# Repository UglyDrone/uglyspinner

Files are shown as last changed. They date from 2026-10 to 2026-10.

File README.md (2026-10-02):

# ESP32 Automated Motor & Propeller Test Stand Firmware

Firmware for the **LILYGO TTGO T7 V1.3 Mini32 (ESP32)** automating static motor and propeller thrust testing.

The system commands an **AM32** electronic speed controller (e.g. **SEQURE 130A ESC**) using high-speed digital **DShot600/300**, decodes real-time **KISS/AM32 ESC telemetry**, measures mechanical thrust/load from an **HX711 UART load cell module**, orchestrates multi-step ramp tests, visualizes real-time performance on a self-contained web dashboard, and exports datasets in standard JSON format.

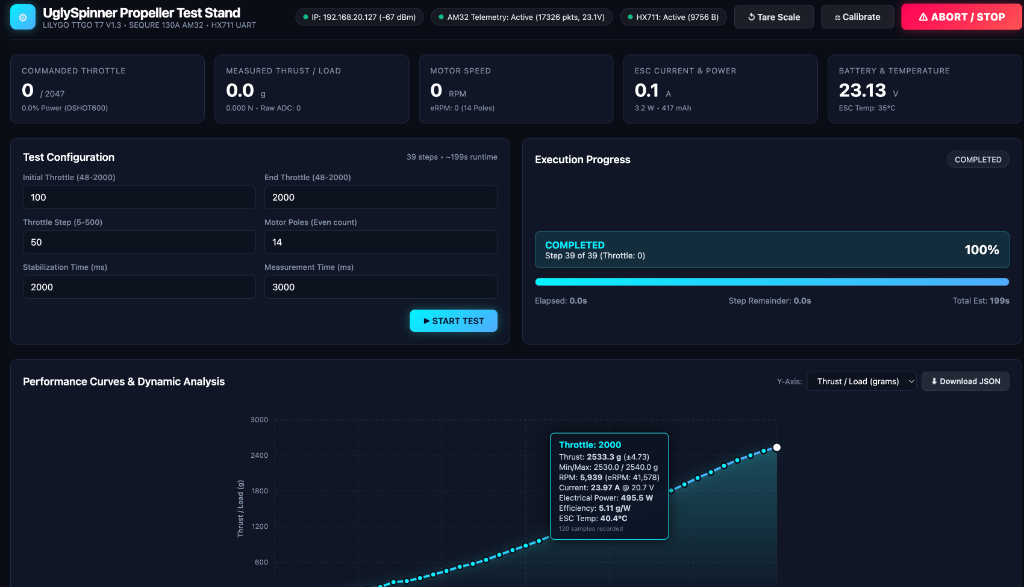
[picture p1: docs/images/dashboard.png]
UglySpinner Web Dashboard


---

## 1. System Architecture & Features

* **Controller**: LILYGO TTGO T7 V1.3 (ESP32 @ 240MHz, 4MB Flash, 1.25MB RAM).
* **Motor Control**: Hardware-timed DShot600 via ESP32 RMT peripheral with fail-safe watchdog.
* **ESC Telemetry**: KISS/AM32 ESC AutoTelemetry protocol (115200 baud, 8N1, CRC8 checked).
* **Thrust Measurement**: HX711-based UART load cell bridge driver with pluggable protocol parsing and zero-tare calibration.
* **Multitasking Core**: FreeRTOS architecture separating motor pulse feeding, telemetry decoding, load acquisition, automated test sequencing, and HTTP serving across dual Xtensa cores.
* **Safety Core**: 
  - Failsafe throttle: Hardware and software force 0 throttle upon boot, reset, Wi-Fi initialization, WebServer initialization, client disconnection, watchdog timeouts, invalid configuration, or malformed HTTP packets.
  - Prominent red Emergency ABORT button in web UI.
  - Pre-test zero throttle verification and ESC arming delay.
* **Modern Web Interface**: Responsive, self-contained single-page dashboard served directly from ESP32 Flash memory (zero CDN dependencies).
* **Data Visualization & Export**: Interactive SVG performance curves (Thrust vs. Throttle, RPM, Current, Efficiency g/W) with error bars ($\pm \text{StdDev}$), tabular data, and full JSON dataset download.
* **Bench Simulation**: Built-in compile-time `MOCK_ESC` and `MOCK_LOADCELL` simulation modes for complete desk testing without spinning a motor.

---

## 2. Bill of Materials (Known Hardware)

The following components comprise the validated, battle-tested hardware configuration:

| Component | Hardware / Model | Specifications & Configuration | Notes |
| :--- | :--- | :--- | :--- |
| **ESP32 Board** | **LILYGO TTGO T7 V1.3 Mini32** | ESP32-D0WDQ6-V3 @ 240MHz, 4MB Flash, internal PSRAM, USB-C | Avoid GPIO 16/17 (physically tied to internal PSRAM bus). |
| **Electronic Speed Controller (ESC)** | **SEQURE SQESC 14130 (130A)** | 6S–14S high-voltage ESC running AM32 firmware (v2.19+) | Enable **Auto Telemetry** in AM32 Configurator. Wire dedicated `TLM` pad to GPIO 32. |
| **Load Cell (Sensor)** | **Straight Bar / Parallel Beam Strain Gauge** | 5 kg, 10 kg, or 20 kg (sized to expected peak motor thrust) | 4-wire Wheatstone bridge (`E+`, `E-`, `A+`, `A-`) connected to HX711 board. |
| **Load Cell Digitizer Module** | **HX711 UART Serial Module** | 24-bit ADC with onboard microcontroller outputting serial stream @ 9600 baud | Supports both ASCII lines (`=000.77\r\n`, `W: ...`) and binary packets. Connected to UART2 (GPIO 22/21). |
| **Brushless Motor** | Brushless Outrunner (e.g. 22xx–28xx series) | 14 poles (7 pole pairs) typical | Configurable pole count in web UI and `src/config.h`. |
| **Main Battery / Power Supply** | LiPo Battery / Bench Power Supply | 4S–6S (e.g. 22.2V–25.2V 6S) rated for expected motor current draw | Power ground and ESP32 GND must be bonded together in a star-ground topology. |
| **Reference Calibration Weight** | Precision test weight | 500 g or 1000 g certified weight | Used with web UI **Calibrate** button to calibrate scale factor. |
| **Enclosure** | **3D Printed Case & Lid** | Parametric OpenSCAD model (`case.scad`) & ready-to-print mesh (`case.stl`) | Protective electronics enclosure for the ESP32 and wiring. |

---

## 3. Hardware Wiring & Pin Assignments

> **IMPORTANT BOARD NOTE**:  
> The **LILYGO TTGO T7 V1.3** is an ESP32 board equipped with internal PSRAM. Pins **GPIO 16** and **GPIO 17** are physically connected to the internal PSRAM bus. Connecting peripherals to GPIO 16/17 will crash the ESP32.  
> This firmware routes the second hardware UART (`UART2`) to **GPIO 22 (RX)** and **GPIO 21 (TX)** on the outer right header, right above 5V and GND, ensuring conflict-free operation.

### Wiring Table

| Signal | ESP32 TTGO T7 Pin | External Device | Device Pin / Wire | Notes |
| :--- | :--- | :--- | :--- | :--- |
| **DShot Signal** | **GPIO 25** | SEQURE 130A ESC | Signal Wire (White/Yellow) | RMT TX Channel 0 |
| **DShot Ground** | **GND** | SEQURE 130A ESC | Signal Ground (Black) | Common ground reference |
| **ESC Telemetry** | **GPIO 32** | SEQURE 130A ESC | Telemetry TX (KISS/AM32 pad) | UART1 RX (115200 baud) |
| **Load Cell RX** | **GPIO 22** | HX711 UART Module | TX Pin | UART2 RX (9600 baud) |
| **Load Cell TX** | **GPIO 21** | HX711 UART Module | RX Pin (optional) | UART2 TX (for tare cmd) |
| **Module VCC** | **5V / VBUS** | HX711 UART Module | VCC (5V or 3.3V) | Outer header pin 8 |
| **System Ground** | **GND** | All Peripherals | GND | **Star-ground topology** |

```
                 +-----------------------------+
                 |  LILYGO TTGO T7 V1.3 ESP32  |
                 |                             |
                 |  [GPIO 25]  -----(Signal)----> [ESC Signal]   SEQURE 130A
                 |  [GND]      <====(Ground)====> [ESC Ground]   AM32 ESC
                 |  [GPIO 32]  <----(TLM TX)----- [ESC Telemetry]
                 |                             |
                 |  [GPIO 22]  <----(UART TX)---- [TX]  HX711 UART
                 |  [GPIO 21]  -----(UART RX)---> [RX]  Load Cell Module
                 |  [5V / VBUS]-----(Power)-----> [VCC]
                 |  [GND]      <====(Ground)====> [GND]
                 +-----------------------------+
```

---

## 4. Explanation of DShot Throttle Units

DShot is a digital protocol transmitting 16-bit serial frames to the ESC. Unlike analog PWM (1000µs–2000µs), DShot is immune to electrical noise and requires no throttle range calibration.

Each 16-bit DShot frame comprises:
* **11 bits** : Commanded value (0 to 2047)
* **1 bit**  : Telemetry request flag
* **4 bits** : CRC checksum `(value ^ (value >> 4) ^ (value >> 8)) & 0x0F`

### Throttle Range Mapping

| Commanded Value | Meaning / Action | Percentage |
| :--- | :--- | :--- |
| **`0`** | **Motor STOP / Disarmed** (Failsafe state) | `0.0%` (Motor disabled) |
| **`1 .. 47`** | **Reserved DShot Commands** (Beep, Direction reversal, Save) | N/A |
| **`48`** | **Minimum Spin Throttle** | `0.05%` (Lowest running speed) |
| **`500`** | Low-mid power range | `22.6%` |
| **`1048`** | Mid-throttle range | `50.0%` |
| **`1500`** | High-power range | `72.6%` |
| **`2047`** | **Maximum Full Throttle** | `100.0%` |

Conversion formula from commanded throttle $T \in [48, 2047]$ to percentage $P$:
$$P = \frac{T - 48}{2047 - 48} \times 100\%$$

---

## 5. Explanation of ESC Telemetry RPM / eRPM Conversion

AM32 and KISS ESCs transmit **Electrical RPM (eRPM)** across the serial telemetry line.

* **eRPM (Electrical RPM)** represents the frequency at which the magnetic field rotates around the motor stator windings.
* **Mechanical RPM (Shaft RPM)** is the actual physical rotation speed of the motor bell and propeller.

A brushless motor contains a specific number of magnetic poles $N$ mounted on the rotor bell (always an even number, commonly 14 poles for 22xx/23xx/28xx motors). The number of magnetic pole pairs $P$ is:
$$P = \frac{N}{2}$$

Because one mechanical rotation requires the magnetic field to pass through all pole pairs:
$$\text{eRPM} = \text{Mechanical RPM} \times \left(\frac{\text{Motor Poles}}{2}\right)$$

Therefore, the mechanical shaft RPM is calculated as:
$$\text{Mechanical RPM} = \frac{\text{eRPM} \times 2}{\text{Motor Poles}}$$

*Example (14 Pole Motor)*:
$$\text{Pole Pairs} = \frac{14}{2} = 7$$
$$\text{If eRPM} = 84,000 \implies \text{Mechanical RPM} = \frac{84,000}{7} = 12,000\text{ RPM}$$

This firmware automatically logs both raw `erpm` and calculated mechanical `rpm`. The motor pole count can be adjusted in `src/config.h` or directly through the web UI before each test run.

---

## 6. Software Architecture & FreeRTOS Tasks

```
  Core 0:                                     Core 1:
+-----------------------------------+       +-----------------------------------+
|  WiFi & Network Management        |       |  DShotMotorTask (100 Hz, Pri Max) |
|  - STA connection & AP fallback   |       |  - RMT DShot pulse feeder         |
|                                   |       |  - Watchdog monitor & safety stop |
|  HTTP Web Server Task             |       |                                   |
|  - Serving HTML/JS UI (PROGMEM)   |       |  EscTelemetryTask (Pri Max - 2)   |
|  - REST endpoints (/api/status,   |       |  - UART1 KISS decoder + CRC8      |
|    /api/start, /api/abort, etc.)  |       |                                   |
+-----------------+-----------------+       |  LoadCellTask (Pri Max - 2)       |
                  |                         |  - UART2 HX711 parser             |
                  |                         |                                   |
                  v                         |  TestRunnerTask (Pri 4)           |
          Shared Mutex-Protected            |  - State machine sequencer        |
             Results & Status  <------------+  - Step stabilization & sampling  |
                                            +-----------------------------------+
```

---

## 7. Configuration & Compilation

The project uses [PlatformIO](https://platformio.org/).

### Configuration File (`src/config.h`)

Open `src/config.h` to customize:
* **Wi-Fi Credentials**:
  ```cpp
  #define WIFI_DEFAULT_SSID       "YourWiFiNetwork"
  #define WIFI_DEFAULT_PASSWORD   "YourWiFiPassword"
  ```
  *(Note: If Wi-Fi fails to connect within 10 seconds, the ESP32 automatically launches an Access Point named `UglySpinner-TestStand` with password `spinnertest` at IP `192.168.4.1`).*
* **Mock Modes**:
  ```cpp
  #define MOCK_ESC                1   // 1 = Simulation, 0 = Hardware SEQURE 130A ESC
  #define MOCK_LOADCELL           1   // 1 = Simulation, 0 = Hardware HX711 UART
  ```
* **Hardware Pins**:
  ```cpp
  #define PIN_DSHOT_SIGNAL        GPIO_NUM_25
  #define PIN_ESC_TELEMETRY_RX    GPIO_NUM_32
  #define PIN_LOADCELL_RX         GPIO_NUM_22
  #define PIN_LOADCELL_TX         GPIO_NUM_21
  ```

### Build Instructions

1. **Build the firmware**:
   ```bash
   pio run
   ```
2. **Flash to TTGO T7 V1.3**:
   ```bash
   pio run --target upload
   ```
3. **Open Serial Monitor**:
   ```bash
   pio device monitor -b 115200
   ```

---

## 8. Desk / Mock-Mode Testing Instructions

To test the complete workflow (web interface, live telemetry updates, interactive charts, abort handling, and JSON export) on your desk before connecting high-power batteries:

1. In `src/config.h`, set:
   ```cpp
   #define MOCK_ESC         1
   #define MOCK_LOADCELL    1
   ```
2. Build and upload: `pio run -t upload`.
3. Open the Serial Monitor. Observe the IP address:
   ```
   [Wi-Fi] Connection established successfully!
   [Wi-Fi] IP Address: http://192.168.1.150/
   ```
4. Open `http://192.168.1.150/` in any web browser.
5. In the **Test Configuration** panel:
   * Initial Throttle: `100`
   * End Throttle: `1000`
   * Step: `100`
   * Stabilization: `1500 ms`
   * Measurement: `2000 ms`
6. Click **`START TEST`**.
7. Observe:
   * Real-time KPI cards updating at 2Hz (Throttle, Load, RPM, Current, Voltage, Temp).
   * Progress bar filling smoothly.
   * Emergency **`ABORT`** test: Click the red button midway through a run. Notice the motor drops to 0 instantly and marks state as `ABORTED`.
8. Complete a full run:
   * The interactive SVG curve renders automatically.
   * Hover over data points to inspect thrust error bars, efficiency, and telemetry.
   * Click **`Download JSON`** to verify the exported dataset.

---

## 9. First-Power-Up Safety Procedure (Propeller Removed)

> [!CAUTION]
> **NEVER ATTACH A PROPELLER DURING FIRST POWER-UP AND CALIBRATION.**  
> A brushless motor on 4S–8S LiPo can cause severe injury if it spins unexpectedly.

Follow this strict checklist when commissioning real hardware (`MOCK_ESC = 0` and `MOCK_LOADCELL = 0`):

1. **Propeller OFF**: Remove all propellers, nuts, and adapters from the motor shaft.
2. **Mounting**: Ensure the motor and test stand are securely clamped to a heavy workbench.
3. **Firmware Configuration**: Set `MOCK_ESC = 0` and `MOCK_LOADCELL = 0` in `src/config.h`. Compile and upload.
4. **Power ESP32 First**: Connect the ESP32 via USB. Open the Serial Monitor at 115200 baud.
   * Confirm console output reads: `[Safety] Enforcing initial zero-throttle state...`
   * Confirm the web page is accessible at the reported IP address.
5. **Power ESC Main Battery**: Connect the LiPo battery to the SEQURE 130A ESC.
   * Listen for the AM32 initialization chime (3 rising beeps indicating power-up, followed by 2 beeps indicating zero-throttle signal detected).
   * If you hear continuous beeping, check GPIO 25 ground reference.
6. **Telemetry Verification**:
   * Inspect the web dashboard. The status badge should show: `AM32 Telemetry: Active`.
   * Current voltage should show your LiPo voltage (e.g., `~25.2V` for 6S).
7. **Motor Spin Direction Test**:
   * Set Initial Throttle = `50`, End Throttle = `60`, Step = `10`, Stabilization = `1000`, Measurement = `1000`.
   * Click **START TEST**.
   * Observe the bare motor shaft spinning smoothly and verify rotational direction.
   * Verify mechanical RPM appears on the dashboard.
8. **Emergency Abort Verification**:
   * Start another low-throttle test and press **ABORT / STOP**.
   * Verify the motor halts within milliseconds.
9. **Loaded Propeller Test**:
   * Only after steps 1–8 succeed: disconnect battery, mount propeller, clear test stand radius of all personnel and loose objects, put on eye protection, and power on.

---

## 10. Hardware Validation & Parser Adaptation

### HX711 UART Module Validation

Because third-party HX711 UART modules utilize different bridge firmware:
1. Connect module TX to GPIO 22 and RX to GPIO 21.
2. The firmware includes an auto-detecting parser in `src/loadcell/loadcell.cpp`:
   * **Binary format**: `[0xAA, 0x55, 4-byte signed raw ADC, Checksum]`
   * **Binary format**: `[0xAA, 0x02, 3-byte 24-bit raw ADC, Checksum]`
   * **ASCII format**: Lines like `W: 123.4 g\r\n`, `=000.77\r\n`, or `+001.234\r\n`
3. If your module uses a proprietary protocol:
   * Open `src/loadcell/loadcell.cpp`.
   * Locate the clearly marked function `UARTLoadCell::parseFrame()`.
   * Adjust packet header and byte offsets according to your module's datasheet.
4. Scale calibration & Tare:
   * Click **Tare Scale** in the web UI with the stand unloaded to zero the load cell.
   * Place a known calibration weight (e.g. 500g) on the load cell.
   * Click **Calibrate** in the top navigation bar, enter the weight in grams, and the ESP32 will automatically compute and persist the calibration factor.

### AM32 ESC Telemetry Validation

The firmware decodes standard 10-byte KISS/AM32 AutoTelemetry:
* **Physical wire**: ESC `TLM` or `TX` pad connected to TTGO T7 **GPIO 32**.
* **Baud rate**: 115200 baud, 8 data bits, no parity, 1 stop bit (8N1).
* **AM32 ESC Config**: In the AM32 Configurator, verify that **"Auto Telemetry"** or **"KISS Telemetry"** is enabled.

---

## 11. Sample Exported JSON Format

When **`Download JSON`** is clicked, the file `propeller_test_dataset.json` is generated:

```json
{
  "metadata": {
    "firmware_version": "1.0.0",
    "dshot_mode": "DSHOT600",
    "telemetry_protocol": "KISS/AM32",
    "start_time_ms": 123456,
    "run_duration_ms": 38400,
    "initial_throttle": 100,
    "end_throttle": 1500,
    "throttle_step": 100,
    "stabilization_ms": 2000,
    "measurement_ms": 3000,
    "motor_poles": 14,
    "load_cell_zero_offset": 84120,
    "load_units": "grams",
    "status": "COMPLETED",
    "abort_reason": ""
  },
  "points": [
    {
      "throttle": 500,
      "load": {
        "mean": 302.80,
        "min": 295.20,
        "max": 309.40,
        "stddev": 2.840,
        "samples": 120
      },
      "rpm": 7420,
      "erpm": 51940,
      "current_a": 5.60,
      "voltage_v": 24.92,
      "temperature_c": 32.5
    }
  ],
  "raw_samples": [
    {
      "t_ms": 125500,
      "el_ms": 2044,
      "thr": 500,
      "load": 301.40,
      "rpm": 7410,
      "erpm": 51870,
      "curr": 5.58,
      "volt": 24.93,
      "temp": 32.5
    }
  ]
}
```

---

## 12. License & Credits

* Developed for LILYGO TTGO T7 V1.3 & AM32 SEQURE 130A ESC testing.
* Uses [DShotRMT](https://github.com/derdoktor667/DShotRMT) for ESP32 RMT DShot pulse generation.
* Uses [ArduinoJson](https://arduinojson.org/) for memory-efficient JSON serialization.

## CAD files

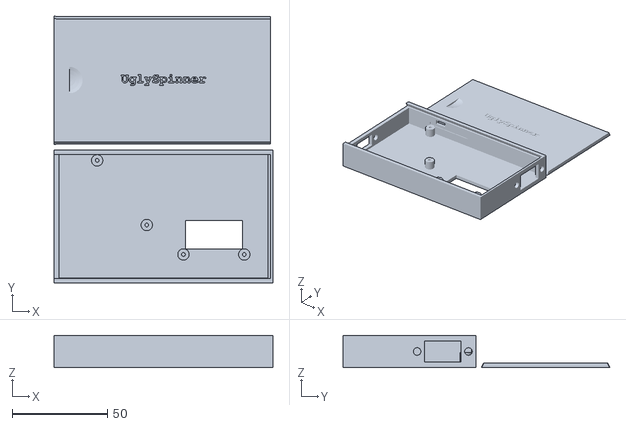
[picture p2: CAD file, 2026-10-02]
case.stl
115.0 x 140.4 x 17.0

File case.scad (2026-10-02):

echo("Built using Ultimate Box Generator v3.10.0");
$fn=360;
// Parts to render. To do more complex opperations disable these and manually call make_box() and make_lid() instead.
show_box=false;	// Whether or not to render the box
show_lid=true;	// Whether or not to render the lid. To make open boxes with no lid set `show_lid=false` and `lid_type=5`.

// General Settings
comp_size_deep = 12; // Depth of compartments
comp_size_x = 110;	 // Size of compartments, X
comp_size_y = 65;	 // Size of compartments, Y
wall = 2.5;		    // Width of wall, see `internal_wall` below for alternate inner wall size.
repeat_x = 1;		// Number of compartments, X
repeat_y = 1;		// Number of compartments, Y
tolerance=.15;      // Tolerance around lid.  If it's too tight, increase this. If it's too loose, decrease it.

// Box Rounding
box_corner_radius=0; // Add a rounding effect to the corners of the box. Anything over `wall` will cause structure and lid problems.
box_corner_radius_axis=[true, true, true]; // Apply rounding on [X, Y, Z] Axis
internal_corner_radius=0; // Add a rounding effect to the inside.
mesh_corner_radius=0; // Leave a radius around each corner of the mesh. May help with bridges.
corner_fn=30;

// Suppress individual walls/sides.
supress_walls_x=[]; // These are the walls running along the X axis. It should be an array of size [repeat_y-1][repeat_x].
supress_walls_y=[]; // These are the walls running along the Y axis. It should be an array of size [repeat_x-1][repeat_y].
// Example for repeat_x=4, repeat_y=3:
//supress_walls_x=[[1,0,1,1],[0,1,0,1]];
//supress_walls_y=[[1,0,1],[0,1,1],[1,1,1]];
supress_sides=false; // [X, Y, X, Y] Cutout/supress some sides. this may behave badly with compartments or mesh.
supress_sides_radius=wall; // Add a rounding to the cutout.
supress_sides_offset=0; // 0, wall, [X, Y, Z] adjust the coutout in all directions. + to grow, - to shrink
supress_sides_fn=30;

// Mesh Settings
// To make rounded corners and no mesh use any `mesh_type` > 0 and set `strut_gap` to a high value.
// 0: No mesh, solid wall.
// 1: Single direction mesh.
// 2: Two direction cross mesh at 90 degree angle to eachother.
// 3: Two direction mesh but mirrored around 90 axis instead or rotated 90 degrees.
// 4: Calculate angle across the diagonal of each opening. You will also want to change `strut_gap` to a large number and set `strut_count_min=1`.
// 5: No mesh, empty wall.
// 6: Honycomb. Also set `strut_width=wall/4` and `strut_gap=wall*2`. Too big of a `strut_gap` may fail to print. Other shapes can be generated with `mesh_fn` and reducing `mesh_inset_padding` may help.
mesh_type=0; // Mesh type, see above.
mesh_rotation=0; // 0-90 degrees.
mesh_alt_rotation=mesh_rotation; // Alternate rotation for top and bottom faces.
mesh_do_sides=true; //[true, true, true, false] Include mesh on each side along axis. [X, Y, X, Y]
mesh_do_bottom=false; // Include mesh on bottom plate.
mesh_do_top=true; // Include mesh on top piece.
mesh_do_interior=false; // Include mesh on inner walls.
mesh_inset_padding=wall; // Leave some solid material before building strut frame. Anything less then wall/2 will likely fall apart.
mesh_fn=mesh_type == 6 ? 6 : 40; // Complexity of curves in meshes, increase for smoother curves.
strut_width=wall*2; // Width of each strut, 0=hollow.
strut_gap=wall; // Width of the air gap between each strut. 0=fine air gaps.
strut_count_min=0; // Optinal minimum number of struts regardless of size calulations.
alt_strut_width=strut_width; // Width of struts going the other direction.
alt_strut_gap=strut_gap; // Width of gap going the other direction.
alt_strut_count_min=strut_count_min; // Optional minimum number of struts regardless of size calculations.
mesh_overflow=0; // Extra rows to add to the mesh. For example in the Honeycomb partial hexegons will be created along the edges.

// Lid Settings
// 0: No Lid. top may be rounded and can cause other rendering changes.
// 1: Lid that slides off in the x direction.
// 2: Lid with a snapped in hinge that rotates open, will make box one wall taller.
// 3: Lid that snaps down onto the box. Also need to change lid_height to around 1.5mm.
// 4: Stackable version of cover 1. The boxes slide into one another. You will need one cover for the last box.
// 5: Oversized lid sits on top and has sides that extend down. (Needs snap support)
// 6: Stacking boxes, will make box 1/2 walls taller.
lid_type=1; // Lid type, see above.
has_thumbhole=true; // Add gripping locations for easy opening.
has_coinslot=false; // Add slot in the top for dropping in components.
has_snap=true; // Add small ridges or snaps to lids to help keep them closed.
lid_type_1_enhanced_snaps=false; // Add enhanced snaps to lid types 1 and 4.
coinslot_x=20;	// Size in X direction
coinslot_y=2.5;	// Size in Y direction
coinslot_corner_radius=0; // rounded coinslot corners if >0; best if less than half the shorter coinslot dimension
z_tolerance=0;   // Z tolerance can be tweaked separately, to make the top of the sliding lid be flush with the top of the box itself.
extra_bottom=.15; // Extra bottom wall height to fit type 4 slider.
hinge_inset=.75; // Size of the hinge connection.
snap_inset=.25; // Amount of overhang for snaps to snap into place.
snap_tolerance=tolerance; // You may need to add tolerance around lid and snaps to let them move freely.
lid_offset=3;		// This is how far away from the box to print the lid
lid_height=wall*2;  // Height of lid. Must be greater than wall width for a `lid_type=5` lid to work. On Lid 3 is the depth of the inset snap.
lid_fn=40; // Increese if printing thicker walls.
lid_alt_offset=false; // Move lid in X instead of Y for printing.

//Internal Structure (You may need to turn off `mesh_do_sides` or `mesh_do_bottom` for good results.)
// You can also use `make_wall()` to manually add your own walls.
// 1: Rounded bottom frame.
// 2: Hexegon bottom frame. (To make this shape perfect set `comp_size_deep` to the width between to edges of the tile and set `comp_size_x` or `comp_size_y` to this: `comp_size_deep / sqrt(3)*2`.
// 3: Rough bottom for make bits sit unevenly. (Partial)
// 4: Verical rounding on corner. Set `internal_size_deep` to `comp_size_deep` and `internal_size_circle` to the shortest `comp_size` for a circle.
// 5: Vertical hexagon. Results may varry.
internal_type=0; // Internal structure, see above.
internal_rotate=false; // On lid axis or rotate to opposite.
internal_size_deep=comp_size_deep/2; // How far into the box to start the internal structure. Should be `comp_size_deep/2` for type 1-2, `wall` for 3, or comp_size_deep for type 4-5.
internal_size_circle=internal_type==1 ? internal_size_deep : internal_size_deep * 2 / sqrt(3); // Use this calculation, or the shorter comp_size for type 4-5.
internal_fn=internal_type==1 || internal_type==4 ? 60 : 6; // Complexity of internal curves, may need to increase for larger or smoother curves.
internal_wall=wall; // Custom size for internal walls.
internal_wall_deep=comp_size_deep; // If set to lower than comp_size_deep then the internal walls will be this tall.

// Text Settings
// 0: None.
// 1: Cutout. Remove material from the wall.
// 2: Raised. If a mesh is used, part of it is filled in to hold the text. Lids 0 and 3 are printed upside down by default. With this option used they will require supports regardless of the orrientation printed.
text_type=1; // Text type, see above.
text_depth=wall/6; // Distance to cutout text or raise it. Use `wall` to cut through.
text_size=5; // Font Size.
text_font="Courier New:style=Bold"; // Use Help -> Font List to see options.
text_message="UglySpinner"; // Message Text, or use `["Line 1", "Line 2"]` for multiline.
text_message_compartments=false;//[["AA", "BB", "CC"], ["AB", "BC", "CD"]]; // Custom text for compartments in top or bottom. Also supports multiline as `[[ ["A", "B"] ]]`.
text_sides=[false, false, true, false]; // Sides to put text on, [X, Y, X, Y]
text_top=true; // Put Text on the top.
text_bottom=false; // Put Text on the bottom.
text_rotation=0; // Rotate the top and bottom text by X degrees. 90 will rotate from the X axis to the Y axis.
text_offset=0; // Text is verticaly centered in the wall. This may look "off" due to casing or hanging tails. You can manually adjust the vertical alignment with this setting.
text_fn=30; // Complexity of the letters, may need to increese with larger fonts.
text_backdrop_scale=[.9, 1.5]; // Font size scaling used on the backdrop when `text_type=2` is used on sides with a mesh.
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

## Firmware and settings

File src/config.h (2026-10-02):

#pragma once

#include <Arduino.h>
#include <driver/gpio.h>
#include <DShotRMT.h>

// =============================================================================
// FIRMWARE VERSION & METADATA
// =============================================================================
#define FIRMWARE_VERSION            "1.0.0"
#define SYSTEM_DEVICE_NAME          "ESP32 Motor/Propeller Test Stand"
#define SYSTEM_HOSTNAME             "uglyspinner"

// =============================================================================
// HARDWARE PIN ASSIGNMENTS (LILYGO TTGO T7 V1.3)
// =============================================================================
// DShot Motor Control Output (RMT Peripheral)
#define PIN_DSHOT_SIGNAL            GPIO_NUM_25

// AM32 / KISS ESC Telemetry Input (Hardware UART1 RX)
#define PIN_ESC_TELEMETRY_RX        GPIO_NUM_32
#define PIN_ESC_TELEMETRY_TX        GPIO_NUM_27 // Assign unused pin (GPIO 27) so UART1 doesn't default to GPIO 10 (SPI flash)

// HX711 UART Load Cell Interface (Hardware UART2)
// On TTGO T7 V1.3 right header: Pin 22 (GPIO22) and Pin 21 (GPIO21) provide conflict-free
// UART2 pins located in the same outer header row right above GND and 5V.
#define PIN_LOADCELL_RX             GPIO_NUM_22 // Connect to Load Cell Module TX
#define PIN_LOADCELL_TX             GPIO_NUM_21 // Connect to Load Cell Module RX

// =============================================================================
// DSHOT & MOTOR CONFIGURATION
// =============================================================================
// DShot mode: DSHOT600 is preferred for low latency (1.67µs bit duration).
// Can be changed to DSHOT300 if long wiring causes signal integrity issues.
#define DEFAULT_DSHOT_MODE          DSHOT300
#define DSHOT_ENABLE_BIDIRECTIONAL  false

static const char *const dshot_mode_name[] = {
    "DSHOT_OFF",
    "DSHOT150",
    "DSHOT300",
    "DSHOT600",
    "DSHOT1200"
};

// DShot Protocol Constants:
// 0           : STOP / Disarm / Failsafe
// 1..47       : Special commands (beeps, rotation direction, etc.)
// 48..2047    : Active throttle range (48 = min spin, 2047 = 100% full power)
#define DSHOT_THROTTLE_STOP         0
#define DSHOT_THROTTLE_MIN_RUN      48
#define DSHOT_THROTTLE_MAX_RUN      2047

// Motor Specifications
#define DEFAULT_MOTOR_POLES         14      // 14 poles = 7 pole pairs (standard 22xx/23xx/28xx motors)

// =============================================================================
// ESC TELEMETRY (AM32 / KISS)
// =============================================================================
#define ESC_TELEMETRY_BAUD          115200  // Standard KISS/AM32 AutoTelemetry baud rate
#define ESC_TELEMETRY_UART_NUM      1       // Hardware UART 1
#define ESC_TELEMETRY_TIMEOUT_MS    1000    // Telemetry freshness timeout

// =============================================================================
// LOAD CELL (HX711 UART MODULE)
// =============================================================================
#define LOADCELL_UART_NUM           2       // Hardware UART 2
#define LOADCELL_BAUD               9600    // Standard baud rate for UART weight bridges (9600 or 115200)
#define LOADCELL_TIMEOUT_MS         1500    // Load cell freshness timeout
#define LOADCELL_DEFAULT_CAL_FACTOR 1.0f    // Calibration factor: load = (raw - offset) * factor
#define LOADCELL_UNIT_STRING        "grams" // Unit of measurement

// =============================================================================
// WI-FI CONFIGURATION
// =============================================================================
// Update these to match your local Wi-Fi network:
#define WIFI_DEFAULT_SSID           "YourWiFiNetwork"
#define WIFI_DEFAULT_PASSWORD       "YourWiFiPassword"

// Fallback SoftAP mode if local Wi-Fi network cannot be reached within 10 seconds:
#define WIFI_AP_SSID                "UglySpinner-TestStand"
#define WIFI_AP_PASSWORD            "spinnertest"
#define WIFI_CONNECT_TIMEOUT_MS     10000

#define HTTP_SERVER_PORT            80

// =============================================================================
// TEST LIMITS & SAFETY WATCHDOG
// =============================================================================
#define SAFETY_ABORT_ON_LOST_TLM    false   // Abort test if telemetry is lost mid-run (set true for live high-power runs)
#define TEST_WATCHDOG_TIMEOUT_MS    1500    // Force throttle to 0 if task heartbeats stop
#define ARMING_DELAY_MS             2500    // Required zero-throttle period before starting test

// Test parameter validation ranges
#define TEST_MIN_THROTTLE_ALLOWED   48
#define TEST_MAX_THROTTLE_ALLOWED   2000    // Safety margin below absolute 2047
#define TEST_MIN_STEP_ALLOWED       5
#define TEST_MAX_STEP_ALLOWED       500
#define TEST_MIN_STABILIZE_MS       500
#define TEST_MAX_STABILIZE_MS       20000
#define TEST_MIN_MEASURE_MS         1000
#define TEST_MAX_MEASURE_MS         30000

// Default test parameter values
#define DEFAULT_INIT_THROTTLE       100
#define DEFAULT_END_THROTTLE        1200
#define DEFAULT_THROTTLE_STEP       50
#define DEFAULT_STABILIZATION_MS    2000
#define DEFAULT_MEASUREMENT_MS      3000

// Maximum stored raw samples in memory during a single test (500 * 32B = 16KB)
#define MAX_RAW_SAMPLES_BUFFER      500

// =============================================================================
// COMPILE-TIME MOCK MODES (FOR DESK/BENCH TESTING WITHOUT PROP/MOTOR)
// =============================================================================
// Set either to 1 to enable software simulation of hardware components.
// With both set to 1, the full web UI, live telemetry, interactive graph,
// test sequencing, and JSON export can be thoroughly tested on the ESP32.
#ifndef MOCK_ESC
#define MOCK_ESC                    0   // 0 = physical SEQURE 130A ESC (DShot on GPIO25, Telemetry RX on GPIO32)
#endif

#ifndef MOCK_LOADCELL
#define MOCK_LOADCELL               0   // 0 = physical HX711 UART on GPIO26(RX)/GPIO27(TX); 1 = simulated physics
#endif

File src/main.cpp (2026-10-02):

#include <Arduino.h>
#include <WiFi.h>
#include "config.h"
#include "motor/dshot_motor.h"
#include "telemetry/esc_telemetry.h"
#include "loadcell/loadcell.h"
#include "test/test_runner.h"
#include "web/web_server.h"
#include <esp_log.h>

static const char* TAG = "Main";

void printBanner() {
    Serial.println("\n=============================================================");
    Serial.println("  ESP32 AUTOMATED MOTOR & PROPELLER TEST STAND");
    Serial.println("  Hardware: LILYGO TTGO T7 V1.3 Mini32 (ESP32)");
    Serial.println("  Firmware Version: " FIRMWARE_VERSION);
    Serial.println("=============================================================");
}

void initWiFi() {
    Serial.println("\n[Wi-Fi] Initializing network subsystem...");
    
    // Safety requirement: Motor defaults to STOP during Wi-Fi initialization
    motorDriver.stop();

    WiFi.setHostname(SYSTEM_HOSTNAME);
    WiFi.mode(WIFI_STA);
    WiFi.begin(WIFI_DEFAULT_SSID, WIFI_DEFAULT_PASSWORD);

    Serial.printf("[Wi-Fi] Connecting to SSID: '%s'", WIFI_DEFAULT_SSID);

    uint32_t startAttempt = millis();
    while (WiFi.status() != WL_CONNECTED && millis() - startAttempt < WIFI_CONNECT_TIMEOUT_MS) {
        delay(400);
        Serial.print(".");
    }

    if (WiFi.status() == WL_CONNECTED) {
        Serial.println("\n[Wi-Fi] Connection established successfully!");
        Serial.printf("[Wi-Fi] IP Address:    http://%s/\n", WiFi.localIP().toString().c_str());
        Serial.printf("[Wi-Fi] Subnet Mask:   %s\n", WiFi.subnetMask().toString().c_str());
        Serial.printf("[Wi-Fi] Gateway:       %s\n", WiFi.gatewayIP().toString().c_str());
        Serial.printf("[Wi-Fi] Signal (RSSI): %d dBm\n", WiFi.RSSI());
    } else {
        Serial.println("\n[Wi-Fi] Connection timed out (Reason 201: NO_AP_FOUND).");
        Serial.println("[Wi-Fi] Scanning visible 2.4GHz Wi-Fi networks in range...");
        int n = WiFi.scanNetworks();
        if (n == 0) {
            Serial.println("  [Wi-Fi] No 2.4GHz networks found. Check antenna if your board has an external IPEX connector.");
        } else {
            Serial.printf("  [Wi-Fi] Found %d visible 2.4GHz network(s):\n", n);
            for (int i = 0; i < n; ++i) {
                Serial.printf("    - %-24s (%d dBm)\n", WiFi.SSID(i).c_str(), WiFi.RSSI(i));
            }
        }
        Serial.println("[Wi-Fi] Starting fallback SoftAP mode...");
        WiFi.mode(WIFI_AP);
        WiFi.softAP(WIFI_AP_SSID, WIFI_AP_PASSWORD);
        Serial.printf("[Wi-Fi AP] SoftAP SSID:     %s\n", WIFI_AP_SSID);
        Serial.printf("[Wi-Fi AP] SoftAP Password: %s\n", WIFI_AP_PASSWORD);
        Serial.printf("[Wi-Fi AP] Web Dashboard:   http://%s/\n", WiFi.softAPIP().toString().c_str());
    }
}

void setup() {
    // 1. Initialize Serial Console
    Serial.begin(115200);
    delay(500);
    printBanner();

    // 2. Safety First: Ensure all outputs are strictly in STOP / OFF state
    Serial.println("[Safety] Enforcing initial zero-throttle state...");

    // 3. Initialize DShot Motor Subsystem
    if (!motorDriver.begin()) {
        Serial.println("[ERROR] Failed to initialize DShot Motor Driver!");
    } else {
        Serial.printf("[Motor] DShot initialized on GPIO%d (Mode: %s)\n", 
                      PIN_DSHOT_SIGNAL, dshot_mode_name[DEFAULT_DSHOT_MODE]);
    }

    // 4. Initialize AM32 / KISS ESC Telemetry Subsystem
    if (!escTelemetry.begin()) {
        Serial.println("[ERROR] Failed to initialize ESC Telemetry!");
    } else {
        Serial.printf("[Telemetry] AM32/KISS Telemetry listening on UART%d RX=GPIO%d (Baud: %d)\n",
                      ESC_TELEMETRY_UART_NUM, PIN_ESC_TELEMETRY_RX, ESC_TELEMETRY_BAUD);
    }

    // 5. Initialize HX711 Load Cell Subsystem
    if (activeLoadCell && activeLoadCell->begin()) {
        Serial.printf("[LoadCell] HX711 Load Cell initialized on UART%d (RX=GPIO%d, TX=GPIO%d, Baud: %d)\n",
                      LOADCELL_UART_NUM, PIN_LOADCELL_RX, PIN_LOADCELL_TX, LOADCELL_BAUD);
    } else {
        Serial.println("[ERROR] Failed to initialize Load Cell Driver!");
    }

    // 6. Initialize Automated Test Runner Task
    if (!testRunner.begin()) {
        Serial.println("[ERROR] Failed to initialize Test Runner coordinator!");
    } else {
        Serial.println("[TestRunner] Automated sequencer task initialized and ready.");
    }

    // 7. Initialize Wi-Fi
    initWiFi();

    // 8. Safety Check before starting web server
    motorDriver.stop();

    // 9. Initialize HTTP Web Server
    if (!webServer.begin()) {
        Serial.println("[ERROR] Failed to start HTTP server!");
    } else {
        Serial.printf("[Web] HTTP Web Server running on port %d\n", HTTP_SERVER_PORT);
    }

    // 10. Print System Status Report
    Serial.println("\n----------------- HARDWARE & SYSTEM STATUS -----------------");
    Serial.printf("  * Controller Board:     LILYGO TTGO T7 V1.3 Mini32\n");
    Serial.printf("  * DShot Control Pin:    GPIO %d (%s)\n", PIN_DSHOT_SIGNAL, dshot_mode_name[DEFAULT_DSHOT_MODE]);
    Serial.printf("  * ESC Telemetry Pin:    GPIO %d RX (115200 8N1)\n", PIN_ESC_TELEMETRY_RX);
    Serial.printf("  * Load Cell UART:       GPIO %d RX, GPIO %d TX (%d baud)\n", PIN_LOADCELL_RX, PIN_LOADCELL_TX, LOADCELL_BAUD);
    Serial.printf("  * MOCK_ESC Mode:        %s\n", MOCK_ESC ? "ACTIVE (Simulated)" : "DISABLED (Hardware)");
    // Print boot reset reason
    esp_reset_reason_t rstReason = esp_reset_reason();
    const char* rst_str = "UNKNOWN";
    switch (rstReason) {
        case ESP_RST_POWERON: rst_str = "POWER_ON"; break;
        case ESP_RST_EXT: rst_str = "EXTERNAL_PIN (EN glitch)"; break;
        case ESP_RST_SW: rst_str = "SOFTWARE_RESTART"; break;
        case ESP_RST_PANIC: rst_str = "EXCEPTION_PANIC (Crash/Abort/bad_alloc)"; break;
        case ESP_RST_INT_WDT: rst_str = "INT_WATCHDOG"; break;
        case ESP_RST_TASK_WDT: rst_str = "TASK_WATCHDOG"; break;
        case ESP_RST_WDT: rst_str = "OTHER_WATCHDOG"; break;
        case ESP_RST_DEEPSLEEP: rst_str = "DEEP_SLEEP"; break;
        case ESP_RST_BROWNOUT: rst_str = "BROWNOUT (Voltage drop on 3.3V/5V)"; break;
        case ESP_RST_SDIO: rst_str = "SDIO"; break;
        default: break;
    }
    Serial.printf("  * Boot Reset Reason:    %s (%d)\n", rst_str, (int)rstReason);
    Serial.printf("  * Web Dashboard:        http://%s/\n", WiFi.isConnected() ? WiFi.localIP().toString().c_str() : WiFi.softAPIP().toString().c_str());
    Serial.println("------------------------------------------------------------\n");
    Serial.println("[System] Ready. Open the web dashboard in your browser to begin testing.\n");
}

void loop() {
    // Non-blocking servicing of incoming HTTP client requests
    webServer.update();

    // Auto-reconnect Wi-Fi if connection drops mid-test
    static uint32_t lastWifiCheckMs = 0;
    if (millis() - lastWifiCheckMs >= 3000) {
        lastWifiCheckMs = millis();
        if (WiFi.status() != WL_CONNECTED && WiFi.getMode() == WIFI_STA) {
            WiFi.reconnect();
        }
    }

    // Periodic heartbeat console report (every 5 seconds)
    static uint32_t lastPrintMs = 0;
    if (millis() - lastPrintMs >= 5000) {
        lastPrintMs = millis();

        LiveTestStatus st = testRunner.getLiveStatus();
        EscTelemetryData esc = escTelemetry.getSnapshot();
        LoadCellSample lc;
        if (activeLoadCell) activeLoadCell->getLatestSample(lc);

        uint32_t dshotFrames = 0, dshotFails = 0;
        uint16_t dshotLastErr = 0, dshotLastRaw = 0;
        motorDriver.getTxStats(dshotFrames, dshotFails, dshotLastErr, dshotLastRaw);

        Serial.printf("[Heartbeat] State: %-12s | Throttle: %4u | DShotTx: %lu (Fail: %lu) | Load: %6.1fg | RPM: %5u | Curr: %4.1fA | Volt: %4.1fV | WiFi: %s\n",
                      st.stateString.c_str(),
                      st.commandedThrottle,
                      (unsigned long)dshotFrames,
                      (unsigned long)dshotFails,
                      lc.loadGrams,
                      esc.rpm,
                      esc.current_a,
                      esc.voltage_v,
                      WiFi.isConnected() ? "Connected" : "AP Mode");
    }

    // Small yield to allow FreeRTOS IDLE task to run
    vTaskDelay(pdMS_TO_TICKS(5));
}

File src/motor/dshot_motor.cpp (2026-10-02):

#include "dshot_motor.h"
#include "telemetry/esc_telemetry.h"
#include <esp_log.h>

static const char* TAG = "DShotMotor";

DShotMotor motorDriver;

DShotMotor::DShotMotor()
    : _dshotDriver(nullptr),
      _mode(DEFAULT_DSHOT_MODE),
      _bidirectional(DSHOT_ENABLE_BIDIRECTIONAL),
      _commandedThrottle(0),
      _armed(false),
      _emergencyStopTriggered(false),
      _lastWatchdogFeedMs(0),
      _taskRunning(false),
      _taskHandle(nullptr) {
}

DShotMotor::~DShotMotor() {
    stop();
    if (_taskRunning) {
        _taskRunning = false;
        vTaskDelay(pdMS_TO_TICKS(50));
    }
    if (_dshotDriver) {
        delete _dshotDriver;
        _dshotDriver = nullptr;
    }
}

bool DShotMotor::begin() {
    ESP_LOGI(TAG, "Initializing DShot motor driver on GPIO%d (Mode: %s, Bidirectional: %s)...", 
             PIN_DSHOT_SIGNAL, dshot_mode_name[_mode], _bidirectional.load() ? "YES" : "NO");

    _commandedThrottle = 0;
    _armed = false;
    _emergencyStopTriggered = false;
    _lastWatchdogFeedMs = millis();

    if (!_reinitDriver()) {
        ESP_LOGE(TAG, "Failed to initialize DShot driver!");
        return false;
    }

    // Start dedicated high-priority motor output FreeRTOS task on Core 1
    _taskRunning = true;
    BaseType_t res = xTaskCreatePinnedToCore(
        _motorTaskStub,
        "DShotMotorTask",
        4096,
        this,
        configMAX_PRIORITIES - 1, // High priority to guarantee regular DShot timing
        &_taskHandle,
        1 // Core 1 (Core 0 handles Wi-Fi and WebServer)
    );

    if (res != pdPASS) {
        ESP_LOGE(TAG, "Failed to create motor task!");
        return false;
    }

    ESP_LOGI(TAG, "Motor driver initialized successfully in safe STOP state.");
    return true;
}

bool DShotMotor::arm() {
    if (_emergencyStopTriggered) {
        ESP_LOGW(TAG, "Cannot arm: Emergency stop flag is active. Clear error first.");
        return false;
    }
    _commandedThrottle = 0;
    _lastWatchdogFeedMs = millis();
    _armed = true;
    ESP_LOGI(TAG, "Motor ARMED. Ready for test commands.");
    return true;
}

void DShotMotor::disarm() {
    _commandedThrottle = 0;
    _armed = false;
    _sendZeroThrottleFrame();
    ESP_LOGI(TAG, "Motor DISARMED. Throttle forced to 0.");
}

bool DShotMotor::setThrottle(uint16_t throttle) {
    // Safety check 1: Emergency stop
    if (_emergencyStopTriggered) {
        _commandedThrottle = 0;
        _sendZeroThrottleFrame();
        return false;
    }

    // Safety check 2: Disarmed state
    if (!_armed && throttle != 0) {
        ESP_LOGW(TAG, "Rejected throttle %u: Motor is not armed!", throttle);
        _commandedThrottle = 0;
        _sendZeroThrottleFrame();
        return false;
    }

    // Safety check 3: Zero throttle is always accepted
    if (throttle == 0) {
        _commandedThrottle = 0;
        return true;
    }

    // Safety check 4: Range validation
    if (throttle < DSHOT_THROTTLE_MIN_RUN || throttle > DSHOT_THROTTLE_MAX_RUN) {
        ESP_LOGE(TAG, "Rejected throttle %u: Out of valid range [%u..%u]!", 
                 throttle, DSHOT_THROTTLE_MIN_RUN, DSHOT_THROTTLE_MAX_RUN);
        _commandedThrottle = 0;
        _sendZeroThrottleFrame();
        return false;
    }

    _commandedThrottle = throttle;
    _lastWatchdogFeedMs = millis();
    return true;
}

void DShotMotor::stop() {
    _commandedThrottle = 0;
    _sendZeroThrottleFrame();
    ESP_LOGI(TAG, "Motor STOP commanded.");
}

void DShotMotor::emergencyStop() {
    _emergencyStopTriggered = true;
    _armed = false;
    _commandedThrottle = 0;
    _sendZeroThrottleFrame();
    ESP_LOGE(TAG, "EMERGENCY STOP TRIGGERED! Motor output disabled.");
}

void DShotMotor::feedWatchdog() {
    _lastWatchdogFeedMs = millis();
}

uint16_t DShotMotor::getThrottle() const {
    return _commandedThrottle.load();
}

bool DShotMotor::isArmed() const {
    return _armed.load();
}

bool DShotMotor::isEmergencyStopped() const {
    return _emergencyStopTriggered.load();
}

dshot_mode_t DShotMotor::getDShotMode() const {
    return _mode;
}

bool DShotMotor::setDShotMode(dshot_mode_t mode) {
    if (mode == _mode) return true;
    _mode = mode;
    return _reinitDriver();
}

bool DShotMotor::setBidirectional(bool bidi) {
    if (bidi == _bidirectional.load()) return true;
    _bidirectional = bidi;
    return _reinitDriver();
}

bool DShotMotor::isBidirectional() const {
    return _bidirectional.load();
}

bool DShotMotor::_reinitDriver() {
    _commandedThrottle = 0;
    _sendZeroThrottleFrame();
#if !MOCK_ESC
    if (_dshotDriver) {
        delete _dshotDriver;
        _dshotDriver = nullptr;
    }

    if (_bidirectional.load()) {
        pinMode(PIN_DSHOT_SIGNAL, INPUT_PULLUP);
        gpio_pullup_en((gpio_num_t)PIN_DSHOT_SIGNAL);
        gpio_set_pull_mode((gpio_num_t)PIN_DSHOT_SIGNAL, GPIO_PULLUP_ONLY);
    } else {
        // Standard DShot: Push-pull output, idle LOW (0V), max drive strength
        pinMode(PIN_DSHOT_SIGNAL, OUTPUT);
        digitalWrite(PIN_DSHOT_SIGNAL, LOW);
        gpio_pullup_dis((gpio_num_t)PIN_DSHOT_SIGNAL);
        gpio_pulldown_en((gpio_num_t)PIN_DSHOT_SIGNAL);
        gpio_set_pull_mode((gpio_num_t)PIN_DSHOT_SIGNAL, GPIO_PULLDOWN_ONLY);
        gpio_set_drive_capability((gpio_num_t)PIN_DSHOT_SIGNAL, GPIO_DRIVE_CAP_3);
    }

    _dshotDriver = new DShotRMT(PIN_DSHOT_SIGNAL, _mode, _bidirectional.load(), DEFAULT_MOTOR_POLES);
    dshot_result_t res = _dshotDriver->begin();
    if (!res.success) {
        ESP_LOGE(TAG, "Failed to initialize DShotRMT! (code: %d)", res.result_code);
        return false;
    }

    if (!_bidirectional.load()) {
        // Enforce maximum drive capability on GPIO pin after RMT channel attachment
        gpio_set_drive_capability((gpio_num_t)PIN_DSHOT_SIGNAL, GPIO_DRIVE_CAP_3);
    }

    ESP_LOGI(TAG, "DShotRMT initialized: mode=%s, bidirectional=%s", 
             dshot_mode_name[_mode], _bidirectional.load() ? "YES" : "NO");

    // Continuous burst of 250 zero-throttle frames (~500ms) to allow AM32 to detect and arm on boot
    for (int i = 0; i < 250; i++) {
        _sendZeroThrottleFrame();
        delay(2);
    }
#endif
    return true;
}

void DShotMotor::_sendZeroThrottleFrame() {
#if !MOCK_ESC
    if (_dshotDriver) {
        _dshotDriver->sendThrottle(0);
    }
#endif
}

void DShotMotor::_motorTaskStub(void *param) {
    DShotMotor *motor = static_cast<DShotMotor*>(param);
    motor->_motorTaskLoop();
}
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

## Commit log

2026-10-02 feat: release v1.0.0 - ESP32 motor & propeller test stand firmware
    - Hardware-timed DShot300/DShot600 motor control on ESP32 RMT peripheral (GPIO 25)
    - Real-time KISS/AM32 ESC telemetry decoding on UART1 (GPIO 32)
    - HX711 UART load cell sensor interface on UART2 (GPIO 22/21) with one-click tare & calibration
    - Complete validated Bill of Materials (BOM) for TTGO T7 Mini32, SEQURE 130A AM32 ESC, HX711 UART module
    - FreeRTOS dual-core architecture with failsafe watchdogs and pre-allocated memory buffers
    - Embedded responsive web dashboard with live KPI metrics, progress tracking, and emergency abort
    - Interactive SVG performance curves with dynamic scaling and ±StdDev error whiskers
    - Full tes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
    [config.h, dshot_motor.cpp, esc_telemetry.cpp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]
2026-10-02 feat(cad): add 3D-printable enclosure model and STL
    - Parametric OpenSCAD case design (case.scad)
    - Ready-to-print 3D mesh (case.stl)
    - Updated README Bill of Materials to include the enclosure
    [case.scad, case.stl]
